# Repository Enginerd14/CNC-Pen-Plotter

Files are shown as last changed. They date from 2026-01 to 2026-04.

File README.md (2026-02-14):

# CNC-Pen-Plotter
A Computer Numerical Controlled machine that translates G-code to drawings on paper by moving a pen along the X and y axes

## Why I chose this project?
I chose to build a CNC pen plotter because it combines electronics and mechanical movement while also helping me develop my PCB and CAD design.

## How to use this project
You could you this for virtually any drawing whether thats to do your homework or to create some artwork. In the future, I am also thinking of upgrading it to amke a router or milling machine. 

## Schematic


## PCB




## PCB 3D render





## 3D Model






## Bill of Materials

| Item | Qty (Project) | Qty (Packs) | Price (£) | Link |
|---|---|---|---|---|
| 600mm Aluminium extrusion | 3 | 1 | 32.05 | [Al extrusion 600mm 4pcs](https://www.aliexpress.com/item/1005003428294239.html) |
| V Wheels | 12 | 1 | 10.34 | [V Wheels set 24pcs](https://www.aliexpress.com/item/1005004275676552.html) |
| Limit Switches | 4 | 1 | 1.48 | [Limit Switches 5pcs](https://www.aliexpress.com/item/1005001834200980.html) |
| NEMA 17 | 2 | 1 | 17.99 | [NEMA 17](https://www.ebay.co.uk/itm/204595546364) |
| Timing Belt 6mm (5m) | 5m | 1 | 4.07 | [Timing belt 6mm](https://www.aliexpress.com/item/32921042288.html) |
| Belt Pulley | 2 | 1 | 4.99 | [Belt Pulley](https://www.aliexpress.com/item/1005010636842055.html) |
| Belt Idler | 2 | 1 | 3.85 | [Idler Pulley](https://www.aliexpress.com/item/1005008093251681.html) |
| ESP32 30pin Devkit v1 | 1 | 1 | 3.86 | [ESP32 Devkit](https://www.aliexpress.com/item/1005006140560853.html) |
| A4988 Motor Driver | 2 | 2 | 2.42 | [A4988](https://www.ebay.co.uk/itm/226914936307) |
| JST 3-pin connectors | 2 | 1 | 1.02 | [JST XH 3 pin 10pcs](https://www.aliexpress.com/item/1005007080333485.html) |
| JST 4-pin connectors | 2 | 1 | 1.23 | [JST XH 4 pin 10pcs](https://www.aliexpress.com/item/1005007080333485.html) |
| JST wire connectors | 2 | 1 | 1.31 | [JST wire connectors](https://www.aliexpress.com/item/1005007277110532.html) |
| Pin sockets (40pin breakaway) | 4 | 1 | 1.82 | [40pin socket 10pcs](https://www.aliexpress.com/item/4001198421663.html) |
| DC barrel jack 5.5mm/2.1mm | 1 | 1 | 0.74 | [DC barrel jack 10pcs](https://www.aliexpress.com/item/1005006827429781.html) |
| 7805 5V regulator | 1 | 1 | 1.36 | [7805 5V](https://www.ebay.co.uk/itm/388949401602) |
| 100µF capacitor | 3 | 1 | 3.39 | [100µF capacitor](https://www.ebay.co.uk/itm/303398108239) |
| 1µF capacitor | 1 | 1 | 1.89 | [1µF capacitor](https://www.ebay.co.uk/itm/355588015874) |
| Pin header breakaway | 10 | 1 | 3.39 | [Breakable pin header](https://www.aliexpress.com/item/1005007564228387.html) |
| 12V 3A power supply | 1 | 1 | 4.51 | [12V 3A power supply](https://www.aliexpress.com/item/4000494270389.html) |
| Servo SG90 | 1 | 1 | 1.23 | [SG90 Servo](https://www.aliexpress.com/item/1005006501322490.html) |
| 5mm(D) 45mm(L) Shaft | 2 | 1 | 2.59 | [5mm/45mm Shaft](https://www.aliexpress.com/item/1005007023343232.html) |
| 10mm Spring (ID 5mm) | 2 | 1 | 0.94 | [10mm spring 5pcs](https://www.aliexpress.com/item/1005010303542920.html) |
| 6mm Spacer M5 | 25 | 3D print | - | Spacer 10pcs |
| M5 Sliding Nuts | 12 | 1 | 1.40 | [Sliding nuts M5 20pcs](https://www.aliexpress.com/item/1005004658668930.html) |
| M5 Bolts | 30 | 1 | 9.54 | [M5 bolts 242pcs](https://www.aliexpress.com/item/1005007197683325.html) |
| M5 40mm Bolts (connecting plates) | 12 | 1 | 2.45 | [M5 40mm 20pcs](https://www.ebay.co.uk/itm/266129484527) |
| M3 4mm (for NEMA 17) | 8 | 1 | 1.15 | [M3 4mm 50pcs](https://www.aliexpress.com/item/4000970993800.html) |
| M5 Nyloc nuts | 30 | 1 | 3.34 | [M5 Nyloc nuts](https://www.aliexpress.com/item/32798773566.html) |
| Multistrand wire | 2m | 1 | 1.25 | [Multistrand wire](https://www.aliexpress.com/item/1005007251965003.html) |
| Cable spiral wrap | - | 1 | 3.32 | [Cable spiral wrap](https://www.aliexpress.com/item/1005003478796768.html) |
| 3D prints delivery | - | - | 10.00 | - |
| PCB cost | - | - | 5.00 | - |
| **TOTAL** |  |  | **£143.92 (~$196.38)** |  |

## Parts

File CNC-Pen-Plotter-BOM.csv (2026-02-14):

Timing Belt 6mm | Quantity in project | Quantity of packs | Total Price £ | URL | TOTAL (£) | TOTAL ($)
600mm Aluminium extrusion | 3 | 1 | 32.05 | Al extrusion 600mm 4pcs | 143.92 | 196.38
V Wheels | 12 | 1 | 10.34 | V Wheels set 24pcs
Limit Switches | 4 | 1 | 1.48 | Limit Switches 5pcs
NEMA 17 | 2 | 1 | 17.99 | NEMA 17
Timing Belt 6mm | 5m | 1 | 4.07 | Timing belt 6mm
Belt Pulley | 2 | 1 | 4.99 | Belt Pulley
Belt idler | 2 | 1 | 3.85 | Idler Pully
Esp32 30pin devkit v1 | 1 | 1 | 3.86 | Esp32 30pin devkit v1
A4988 Motor Driver | 2 | 2 | 2.42 | A4988
JST 3 pin connectors | 2 | 1 | 1.02 | JST XH 2.54 3 pin connector 10pcs
JST 4 pin connectors | 2 | 1 | 1.23 | JST XH 2.54 4 pin connector 10pcs
JST wire connectors | 2 | 1 | 1.31 | JST wire connectors
Pin sockets | 4 | 1 | 1.82 | 40pin socket 10pcs Breakaway
DC barrel jack | 1 | 1 | 0.74 | DC barrel jack 5.5mm/2.1mm 10pcs
7805 5V reg | 1 | 1 | 1.36 | 7805 5V
100microfarads capacitor | 3 | 1 | 3.39 | 100mf capacitor
1uf microfarads capacitor | 1 | 1 | 1.89 | 1uf
Pin header Breakaway | 10 | 1 | 3.39 | breakable pin header
12V 3A power supply | 1 | 1 | 4.51 | 12V 3A power supply
Servo SG90 | 1 | 1 | 1.23 | SG90 Servo
5mm(D) 45mm(L) Shaft | 2 | 1 | 2.59 | 5mm/45mm Shaft
10mm spring ID5mm | 2 | 1 | 0.94 | 10mm spring 5pcs
6mm Spacer M5 | 25 | 3D print these | - | Spacer 10pcs
M5 Sliding Nuts | 12 | 1 | 1.4 | Sliding nuts M5 20pcs
M5 Bolts | 30 | 1 | 9.54 | M5 bolts 242pcs
M5 40mm (connecting plates) | 12 | 1 | 2.45 | M5 40mm 20pcs
M3 4mm for NEMA 17 | 8 | 1 | 1.15 | M3 4mm 50pcs
M5 Nyloc nuts | 30 | 1 | 3.34 | M5 Nyloc nuts 100pcs
Multistrand wire | 2m | 1 | 1.25 | Multistrand wire
Cable spiral wrap | - | 1 | 3.32 | Cable spiral wrap
3D prints delivery | - | - | 10
PCB cost | - | - | 5

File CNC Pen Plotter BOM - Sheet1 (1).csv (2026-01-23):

Timing Belt 6mm | Quantity in project | Quantity of packs | Unit Price £ | Total Price £ | URL | TOTAL (£) | TOTAL ($)
600mm Aluminium extrusion | 3 | 1 | 11.85 | 47.37 | Al extrusion 600mm 4pcs | 185.03 | 251.73
V Wheels | 12 | 1 | 0.44 | 10.54 | V Wheels set 24pcs
Limit Switches | 4 | 1 | 0.3 | 1.48 | Limit Switches 5pcs
NEMA 17 | 2 | 1 | 7.18 | 21.53 | NEMA 17
Timing Belt 6mm | 3m | 1 | 4.14 | 4.14 | Timing belt 6mm
Belt Pulley | 2 | 1 | 1 | 5 | Belt Pulley
Belt idler | 2 | 1 | 2.4 | 4.79 | Idler Pully
Esp32 30pin devkit v1 | 1 | 1 | 3.88 | 3.88 | Esp32 30pin devkit v1
A4988 Motor Driver | 2 | 2 | 1.17 | 2.34 | A4988
JST 3 pin connectors | 2 | 1 | 0.1 | 1.02 | JST XH 2.54 3 pin connector 10pcs
JST 4 pin connectors | 2 | 1 | 0.12 | 1.23 | JST XH 2.54 4 pin connector 10pcs
JST wire connectors | 2 | 1 | 0.148 | 1.48 | JST wire connectors
8pin Pin socket | 4 | 1 | 0.1 | 1.02 | 8pin socket 10pcs
DC barrel jack | 1 | 1 | 0.12 | 1.21 | DC barrel jack 5.5mm/2.1mm 10pcs
7805 5V reg | 1 | 1 | 0.104 | 1.04 | 7805 5V
100microfarads capacitor | 3 | 1 | 0.1 | 2.08 | 100mf capacitor
1uf microfarads capacitor | 1 | 1 | 0.117 | 2.34 | 1uf
15pin socket | 2 | 1 | 0.124 | 1.24 | 15pin socket
Pin header Breakaway | 10 | 1 | 0.339 | 3.39 | breakable pin header
12V 3A power supply | 1 | 1 | 4.51 | 4.51 | 12V 3A power supply
Servo SG90 | 1 | 1 | 1.23 | 1.23 | SG90 Servo
5mm(D) 45mm(L) Shaft | 2 | 1 | 0.37 | 2.59 | 5mm/45mm Shaft
10mm spring ID5mm | 2 | 1 | 0.1 | 1.04 | 10mm spring 10pcs
6mm Spacer M5 | 25 | 3 | 0.04 | 1.14 | Spacer 10pcs
M5 Sliding Nuts | 12 | 1 | 0.09 | 1.79 | Sliding nuts M5 20pcs
M5 Bolts | 30 | 1 | 0.04 | 9.54 | M5 bolts 242pcs
M5 40mm (connecting plates) | 12 | 1 | 0.21 | 4.15 | M5 40mm 20pcs
M3 4mm for NEMA 17 | 8 | 1 | 0.02 | 1.15 | M3 4mm 50pcs
M5 Nyloc nuts | 30 | 1 | 0.33 | 3.34 | M5 Nyloc nuts 100pcs
Multistrand wire | 2m | 1 | 1.25 | 1.25 | Multistrand wire
Cable spiral wrap | - | 1 | 3.32 | 3.32 | Cable spiral wrap
3D prints delivery | - | - | - | 10
PCB cost | - | - | - | 5
Shipping |  |  |  | 17.86

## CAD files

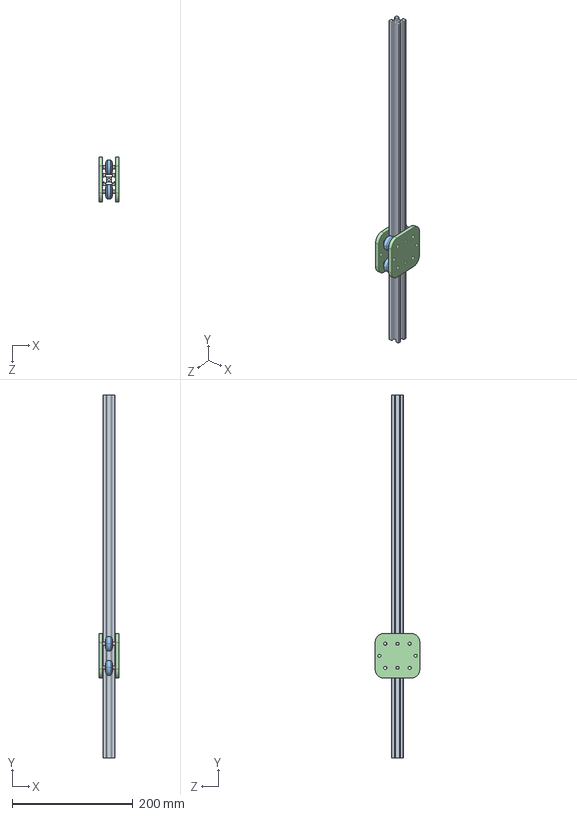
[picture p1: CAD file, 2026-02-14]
CAD/XaxisAssembledFixed.STEP
32.9 x 600.0 x 74.0 mm
Xaxis
VWheel x 4
XtoYConnectingPlateFixed x 2
VWheelSpacer x 8

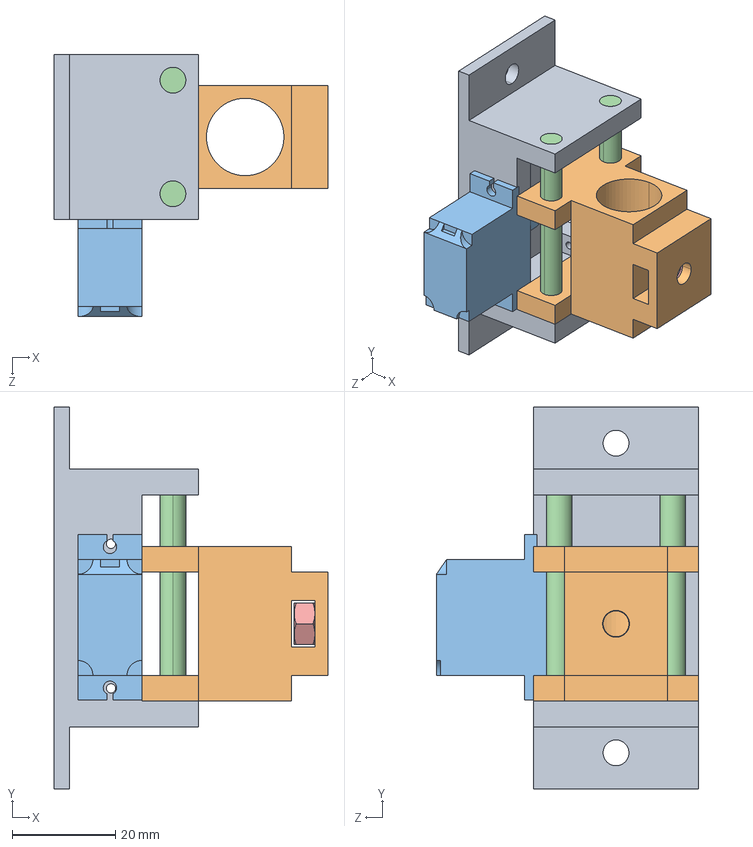
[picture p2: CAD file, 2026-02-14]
CAD/PenAssembley.STEP
53.0 x 74.0 x 50.8 mm
PenPlateGuide
PenHolderPlateFixed
ServoSG90_Predeterminado
PenShaft x 2
M5Nut

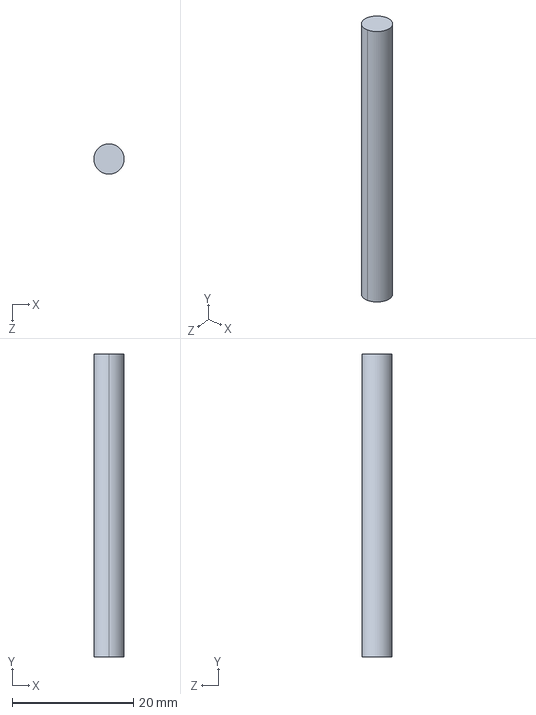
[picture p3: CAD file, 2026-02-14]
CAD/PenShaft.step
5.00 x 50.0 x 5.00 mm

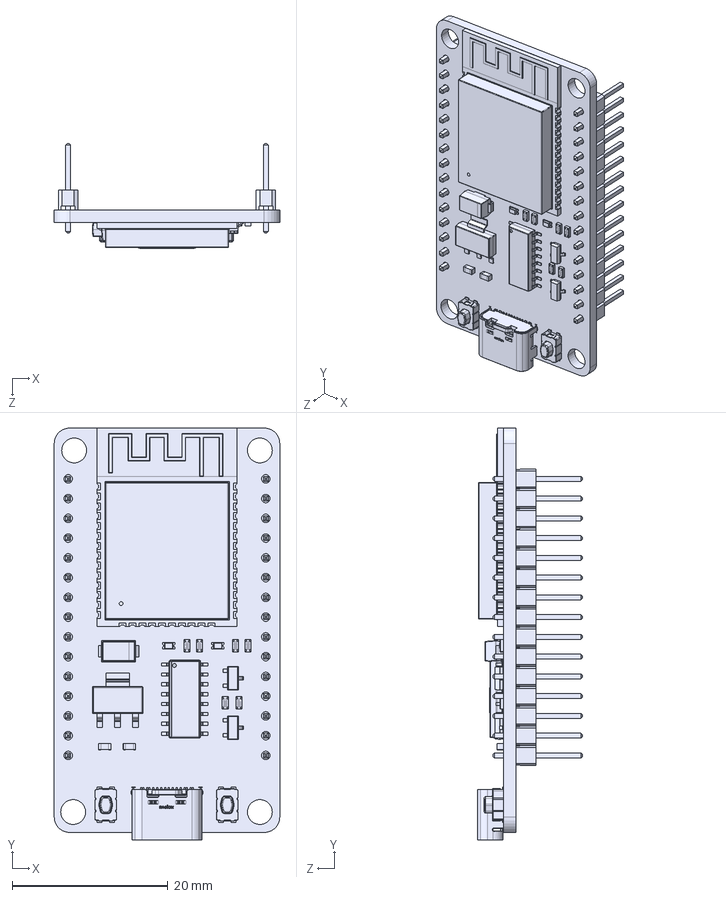
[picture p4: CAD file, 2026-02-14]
PCB Render/esp32_30pin.STEP
29.0 x 53.0 x 13.5 mm
6130xx11121_PIN.step x 30
61301511121.step x 2
SMA.step
0603 cap.step x 2
C&K - KMR7.step x 2
0603 resistor.step x 6
LED 0603 Lens GREEN.step x 2
LED 0603 Base GREEN.step x 2
SOT-23-3.step x 2
Leader.step x 16
SOT-223.step
7508963920.step
1.step
2.step
3.step
4.step
5.step
6.step
7.step
8.step
9.step
Notch.step
Molex.step

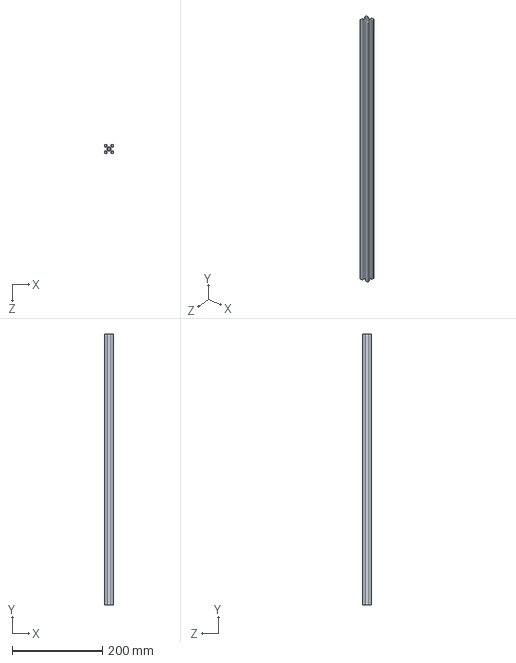
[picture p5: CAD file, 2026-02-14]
CAD/Xaxis.step
20.0 x 600.0 x 20.0 mm

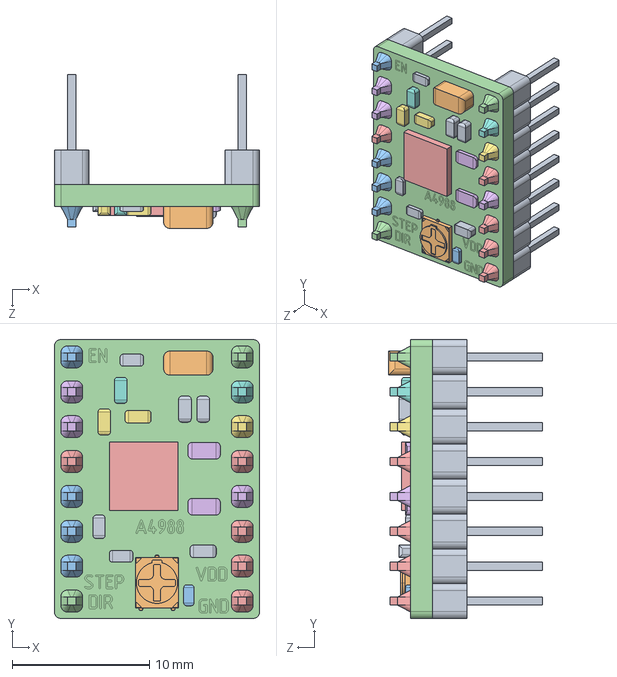
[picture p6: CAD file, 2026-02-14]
PCB Render/A4988-Stepper-Driver-WithPins.STEP
15.0 x 20.3 x 11.2 mm

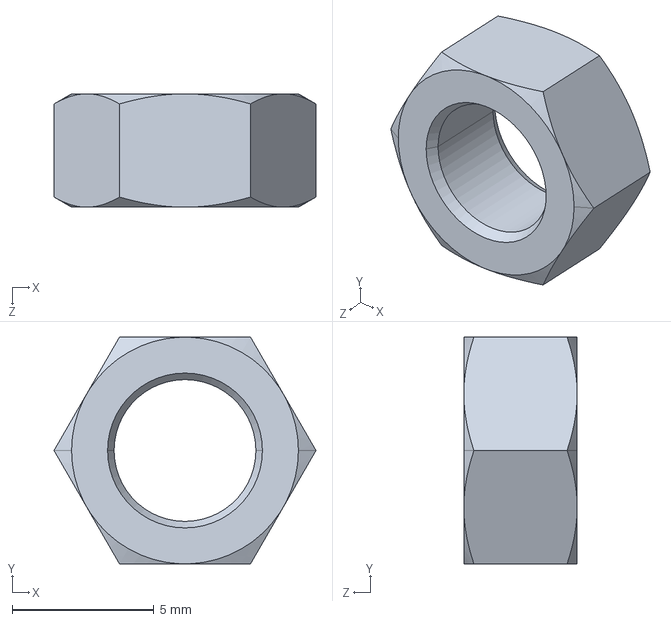
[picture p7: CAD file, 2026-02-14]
CAD/M5Nut.step
9.24 x 8.00 x 4.00 mm

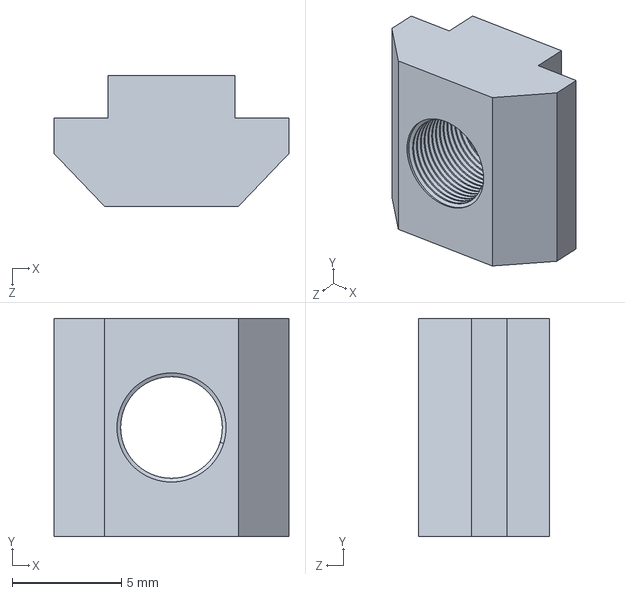
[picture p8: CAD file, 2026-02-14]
CAD/AlExtrusionFixingNut.step
10.8 x 10.0 x 5.99 mm

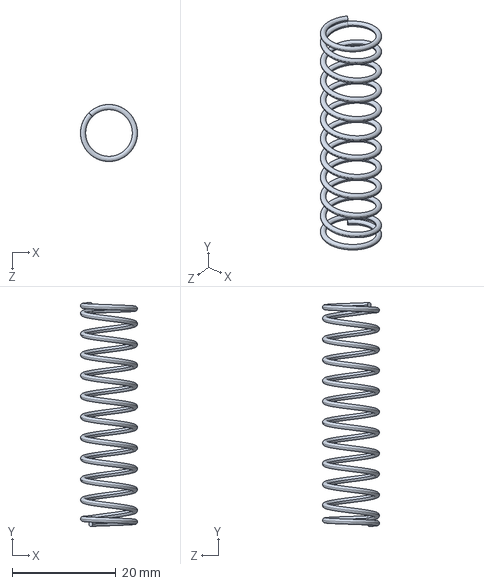
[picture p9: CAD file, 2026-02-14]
CAD/Spring.step
11.0 x 43.2 x 11.0 mm

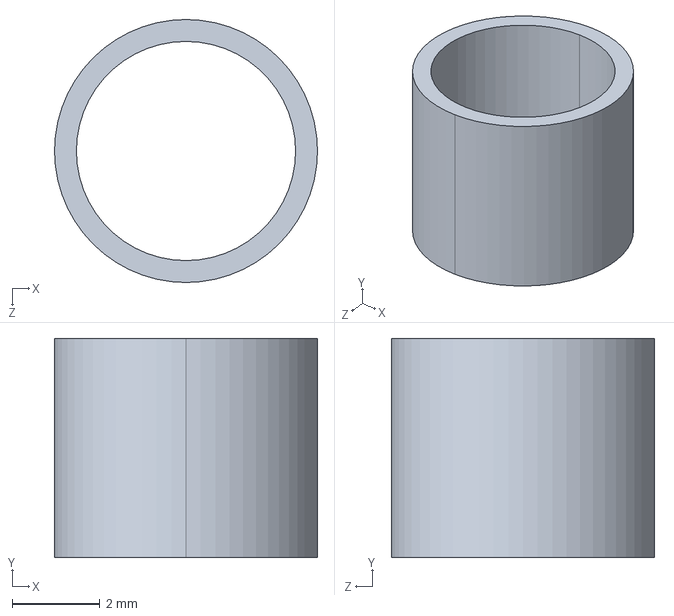
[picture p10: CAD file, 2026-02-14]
CAD/VWheelSpacer.step
6.00 x 5.00 x 6.00 mm

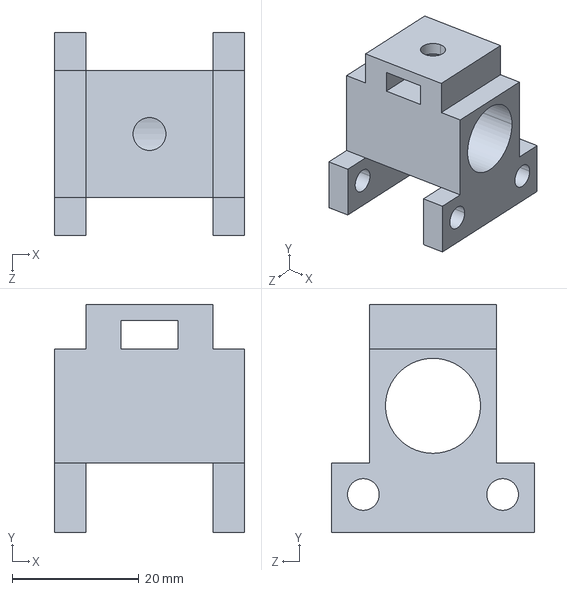
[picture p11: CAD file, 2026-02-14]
CAD/PenHolderPlateFixed.step
30.0 x 36.0 x 32.0 mm

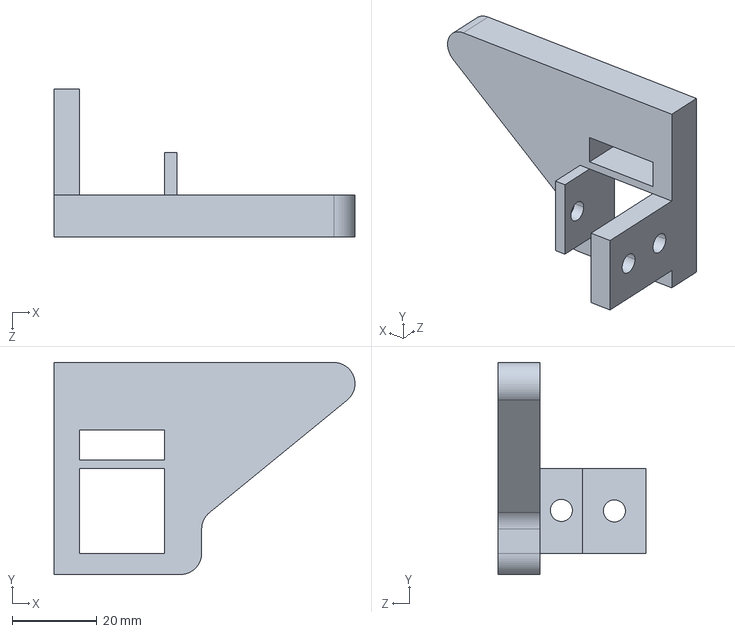
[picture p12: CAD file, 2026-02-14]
CAD/SidePlateIdlerInverted.step
71.0 x 50.0 x 35.0 mm

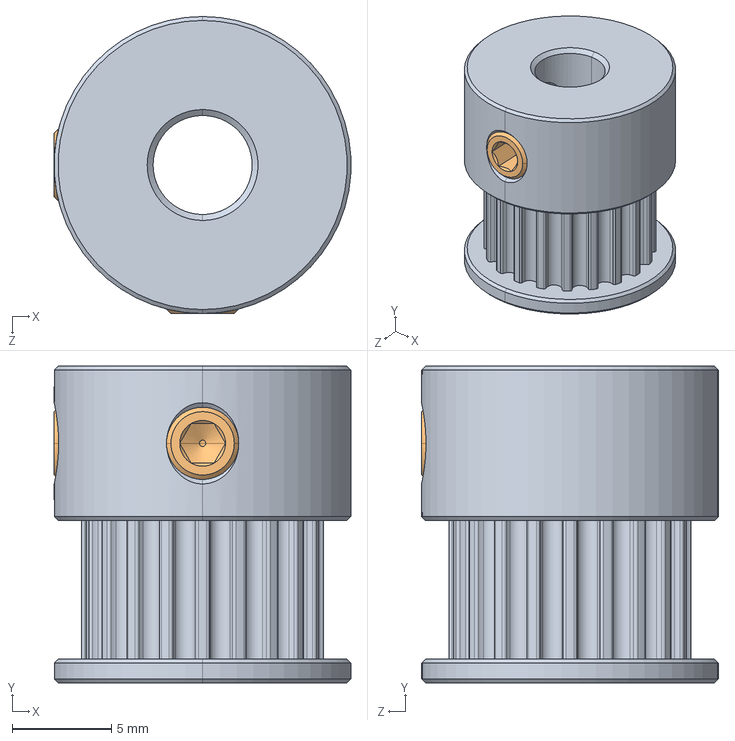
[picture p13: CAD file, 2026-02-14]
CAD/GT2_Pully_20T_6mm.STEP
15.0 x 16.0 x 15.0 mm
GT2_Pulley_20T_6mm.step
M4x5-Screw028.step x 2

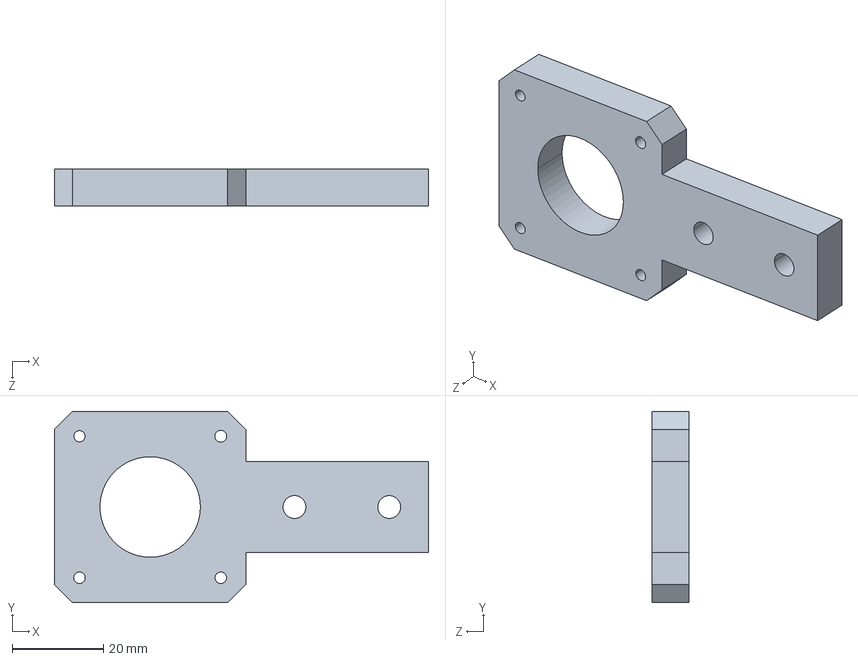
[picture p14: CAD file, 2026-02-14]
CAD/YaxisMotorPlate.step
81.9 x 41.9 x 8.00 mm

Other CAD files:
CAD/YaxisAssembledFixed.STEP
CAD/YaxisIdlerPlate.step
CAD/SidePlateMotor.step
CAD/SidePlatePCBInverted.step
CAD/GT2_Idler_Smooth_6mm.STEP
CAD/Limit Switch.STEP
CAD/NEMA17.step
CAD/PenPlateGuide.step
CAD/ServoSG90.step
CAD/SidePlateNoMotor.step
CAD/VWheel.step
CAD/XtoYConnectingPlateFixed.step
CAD/Yaxis350mm.step

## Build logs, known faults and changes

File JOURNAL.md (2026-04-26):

This is where I will document the process of building my **CNC pen plotter**
## Total Hours: 54.8

## 09/12/25

I began producing a design of the outcome in Solidworks. First, I produced the components I will use seperately. I produced a 2020 aluminium extrusion. These will create the two axes: the X-axis and the Y-axis. Then I found 3D models of the V-Wheels that will glide along the rails. The V-Wheels were then nestled between two plates using 5mm spacers. On this plate, the X-axis will be attached. I repeated this combination for the Y-axis where the plates will be attached to the pen holder. I then created an assembly of both the X-axis and Y-axis. 






Once I had created the separate axes, I created the full assembly. I created Sliding nuts to fix the componets onto the aluminium extrusion.



Hours Spent: 5.5Hrs

## 10/12/25

I noticed that the V-Wheels were too deep within the extrusion so I had to recreate the separate axes assemblies an then the full axes assembly.








Hours Spent: 5Hrs

## 11/12/25

I found 3D models of the NEMA 17 motors and the Pulley and Idlers used. I created bases for the Y axis extrusion to sit on and the mechanical componets to attach to. 






Hours Spent: 4.5Hrs

## 12/12/25

I began creating the plates to connect the motor and pulley system to the X axis.



Hours Spent: 3Hrs

## 13/12/25

Today, I began assembling the entire project. 




Hours Spent: 5.5Hrs

## 14/12/25

I added in Limit switches and began thinking abot the design of the Pen holder. 



Hours Spent: 2.5Hrs

## 15/12/25

I created the different parts of the Pen holder mechanism. I decided that I would make it attachable to the existing plate on the X-axis.
- Existing Plate 
  
- Pen Holder  
  
- Pen holder Guide 
  
- shaft pen holder will glide along 
  
- Full Assembly with servo motor 
  
- Attached to axis 

- Full Model so far 
  

Hours Spent: 5Hrs

## 16/12/25

Today, I began considering the Circuit components required for this project.

- Microcontroller - I decided on the arduino uno for simplicity
- Stepper motors - I chose the NEMA 17, probably the most common stepper motor used in low cost 3D printers and CNC machinery
- Stepper motor drivers - I descided on the A4988 
- Limit switches
- Servo motor - I am using the SG90

This means I can use GRBL to translate the G code into movement.
However, there are some issues. The motors  need a 12V supply whereas the servo and arduino uno only use 5V. Therefore, I will use a buck regualtor, the LM2596 to step down the 12V to 5V. 

You can find pre-made shields for the arduino uno with 4 A4988 motor drivers but thats boring, so I decided to create my own on KiCad :) But due to the complexity and time constraints, I decided I will use a pre-made LM2596 Module. 

Hours Spent: 2Hrs

## 17/12/25

I began creating the schematic for the PCB using datasheets and various online tutorials. KiCad doesn't have a symbol footprint for the LM2596 premade module so I created my own using 3 pads: one for Voltage In, one for Voltage Out and one for GND. 



Hours Spent: 2Hrs

## 18/12/25

Today, I created the PCB using the schematic. I wanted my PCB to stack on top of the arduino just like the premade shield so I used Pin headers to connect to the arduino. I also had to make my own footrpint for the LM2596 Module whcih just consisted of 3 pads. 





Hours Spent: 3Hrs

## 19/12/25

While creating my BOM, I realised tht majority of the power supplies used a barrel jack so I switched out my screw terminal for a barrel jack and remade the PCB.






Hours Spent: 2Hrs

## 20/12/25

I added the electronics to my CAD model and noticed that the stands and plates were too thin so I bulked them out. I now had a finished assmebly of my CNC Pen plotter. 






Hours Spent: 3.5Hrs

## 21/12/25

I completed the BOM and started to upload everything onto my repo, ready for sumbission. 

Hours Spent: 2Hrs

## 22/01/26

I recieved feedback on my project and chose to remake my PCB. This time I decided to use an ESP32 as I was told the Arudino uno was outdated and expensive. I remade the PCB using the same motor drivers and motors and limit switches. I used an 7805 5V regulator to step down the voltage for the ESP32.



Once I had finished with my schematic, I began designing my PCB. I decided not to make the A4988 and the ESP32 directly soldered to the board and used pin sockets instead to ensure there will be no damage to the components while soldering and if damage occurs, they are easily swappable. 





Once I finished the designs I began writing a simple program to test whether the functions work as expected. Then I updated my BOM, my ReadMe and journals on github ready to submit. 

Hours Spent: 4Hrs

## 18/03/26

After two weeks I finally received all the parts and began assembling it all together. I began by assembling the extrusions to the stands using the M5 screws and nuts. Then I attached the plates to the extrusions and attached all 3 extrusions together. While doing this I overtightened some of the screws causing the 3d printed stands to crack where the screws were causing more stress. So I used a soldering iron to melt the filament back into place although it was now significantly weaker then before. I struggled to fit the 40mm bolt through the plates and the spacers and the v wheels and I had to do this for 3 different plates so I took quite a while just to assemble the basic frame. I also screwed the motors down and attached the pulleys to the motors and the correct printed parts where they were needed. Then I realised I couldn't fit the belt through so I had to undo it all fit the belt, cut it to the right length, ziptie to down and re assemble the casing. I finished the assembly by fitting the pen lift mechanism together. However I found that the springs were too small and that they didn't actually fit on the metal shaft. While looking for new ones I realise I didn't need it because gravity exists and if the servo tilts to the correct position it should just fall down. So I continued assembling the pen lift and it wasn't long till I ran into another problem. The shaft didn't fit through the pen lift holes so couldn't be assembled. Rather than reprintg and waiting I just drilled the hole bigger so it would fit but it took a while as I had to be careful not to break it as the hole was already near the edge. I put in the screw and the nut to hold the pen in place and finished by again attaching it to the extrusion with the long 40mm bolts. I now had a fully assembled frame and was ready for the PCB.




Hours Spent: 2.1Hrs

## 25/03/26

Now that I had all the PCB parts and had a frame ready too, I began to solder my PCB. I soldered all the components on to the PCB. It took a while to solder the pin sockets because they were surprisingly difficult to cut however I was just using scissors so I guess that makes sense :) then when I powered it on I got an error light on the esp32 and the computer could not recognise it at all. So I got out my multimeter and tested every single pin 3 times but I didn't really know what I was looking for so didn't find much. I looked at every connection against the schematic and couldn't find any thing wrong. Until I realised the HUGE mistake. Kicad didn't have the esp32 that I was using so I used 1x15 pin sockets instead to connect everything in the schematic but when designing the PCB, the socket was effectively upside down so the connections were all wrong for one side of the PCB. Blueprint is ending really soon and luckily I was allowed to buy the premade CNC module as I had managed to save a lot for money on the extrusions. Hopefully that will work when it arrives and I will be able to remake the PCB correctly in the future.





Hours Spent: 1.8Hrs

## 25/04/26

The CNC shield arrived and I tested it and it turned on and looked good. So I began downloading grbl. Once I downloaded it on my PC I used Arduino ide to flash it to the R3. The. I installed the universal g code sender to the connect the board and send the instructions to the motors. This all took a lot longer than it should have because it was the first time I had done something like this with coding and flashing so I spent a lot of time looking at tutorials. When I tested it, it didn't work. I realised that I need to connect the power supply to the shield not the Arduino so I soldered a 3.5mm jack to the screw terminal that provided power to the CNC shield. Then when I powered it on, the g code sender immediately recognised the board. I then calibrated the step and the direction of the motors and the coordinates and all and then it was ready to test. However the servo cable was too short but I don't really have time to fix that rn so we we shall ignore that for now and come back to it in the future. To test it, I managed to draw a simple square using the machine. But I have to tape the paper down so it doesn't shift. I couldn't really test with anything complicated yet because it was late at night and very noisy and I am supposed to be revising. But I know it works now :)

https://youtu.be/4iL55zWHgNk?si=hgiViPPwNMbE4X7G




Hours Spent: 1.4

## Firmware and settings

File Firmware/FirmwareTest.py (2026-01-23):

from machine import Pin
import time

X_STEP   = Pin(12, Pin.OUT)
X_DIR    = Pin(13, Pin.OUT)
X_LIMIT  = Pin(15, Pin.IN, Pin.PULL_UP)

Y_STEP   = Pin(25, Pin.OUT)
Y_DIR    = Pin(14, Pin.OUT)
Y_LIMIT  = Pin(4, Pin.IN, Pin.PULL_UP)

ENABLE   = Pin(26, Pin.OUT)

STEP_DELAY = 0.001
MOVE_STEPS = 2000

ENABLE.value(0)

def step_motor(step_pin, delay):
    step_pin.value(1)
    time.sleep(delay)
    step_pin.value(0)
    time.sleep(delay)

def move_axis(step_pin, dir_pin, limit_pin, direction):
    dir_pin.value(direction)
    for i in range(MOVE_STEPS):
        if limit_pin.value() == 0:
            break
        step_motor(step_pin, STEP_DELAY)

while True:
    move_axis(X_STEP, X_DIR, X_LIMIT, 1)
    time.sleep(1)

    move_axis(X_STEP, X_DIR, X_LIMIT, 0)
    time.sleep(1)

    move_axis(Y_STEP, Y_DIR, Y_LIMIT, 1)
    time.sleep(1)

    move_axis(Y_STEP, Y_DIR, Y_LIMIT, 0)
    time.sleep(3)

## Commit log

2025-12-10 Create Cad
2025-12-10 Create PCB
2025-12-14 Document assembly process and update hours in JOURNAL.md
    Added images and details about the assembly process for the X-axis and Y-axis in Solidworks. Updated hours spent on the project.
2025-12-14 Enhance journal entries with design details and updates
    Updated the journal with additional details about the design process, including the use of 3D models for components and the assembly of the project. Added new entries for the dates 12/12/25, 13/12/25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
2025-12-21 Add images to README for PCB and 3D Model sections
2025-12-21 Document GRBL setup and power supply details
    Added notes on GRBL compatibility and power supply considerations for motors.
2025-12-21 Update README with schematic, PCB, and 3D model images
2025-12-21 Add PCB cost entry to README
    Added PCB cost entry to the cost table.
2025-12-21 Revise project motivation in README
    Updated the project motivation to include PCB and CAD design.
2026-01-23 Add PCB and shipping costs to README
2026-01-23 Update and rename CNC Pen Plotter BOM - Sheet1 (1).csv to CNC Pen Plotter BOM.csv
    [CNC Pen Plotter BOM.csv]
2026-01-23 Document feedback and PCB redesign with ESP32
    Added journal entry for project feedback and PCB remake.
2026-01-23 Revise journal entry for PCB redesign and updates
    Updated journal entry with new project details and images.
2026-01-23 Add firmware test script for motor control
2026-02-14 Update Bill of Materials section in README
2026-02-14 Enhance README with PCB render and model images
    Added PCB 3D render images and updated 3D model section.
2026-02-14 Update README.md
    Added a section about the project's schematic.
